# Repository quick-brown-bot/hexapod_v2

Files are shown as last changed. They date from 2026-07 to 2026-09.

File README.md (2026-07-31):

# Hexapod

An ESP32-powered hexapod robot built as a long-term robotics and embedded systems project.

The goal is not just to make a robot walk, but to learn and at the same time build a platform that is easy to experiment with, tune, and extend. Most robot behavior is configurable at runtime, control inputs are transport-independent, and the motion stack is organized into separated components.

The project combines firmware, hardware design, and system documentation in a single repository.

> 6 legs, 18 servos, ESP32 mainboard, distributed RP2040 leg controllers over
> an RS485 bus, per-servo current sensing.

This is a continuation of the original [Hexabot](https://github.com/quick-brown-bot/hexapod) project, developed here in
[`hexapod_v2`](https://github.com/quick-brown-bot/hexapod_v2). It differs from
the original mainly in electronics architecture — distributed RP2040 leg
controllers over RS485 instead of a single ESP32 driving all servos directly —
and adds new features such as per-servo current sensing.

---

## What Is In This Repository

The repository contains software and hardware assets used to develop and validate the robot.

```text
firmware/
├── mainboard/             ESP32 mainboard firmware (RS485 master)
├── leg/                   RP2040 leg controller firmware
└── mainboard_rs485_test/  Standalone RS485 bring-up/benchmark tool

hardware/
├── mainboard/             MainBoard schematic (ESP32 + IMU + RS485 master)
├── legboard/               LegBoard schematic (RP2040, servo PWM, current sensing)
└── powerboard/            MainPowerBoard schematic (battery, fusing, UBEC/SBEC)

docs/
├── architecture/          System architecture, hardware and mechanics
├── interfaces/            RS485, RPC, WiFi, Bluetooth, controller driver protocols
├── configuration/         Configuration platform design
├── development/           Build, flash, and dev workflow
└── plans/                 Project-wide backlog and research items
```

Mainboard firmware overview: [firmware/mainboard/README.md](firmware/mainboard/README.md)

The main firmware is built around a fixed 100 Hz control loop and a modular motion pipeline:

```text
Controller Input
        ↓
Gait Scheduler
        ↓
Foot Trajectory Generation
        ↓
Inverse Kinematics
        ↓
Motion Limiting
        ↓
Servo Outputs
```

---

## Current Technical Highlights

## Effort Summary

| Effort Area | Scope | Current Status | Notes |
| --- | --- | --- | --- |
| Locomotion Pipeline | Command mapping, gait scheduler, swing trajectory, whole-body IK | Implemented | Runs in a fixed 100 Hz control loop |
| KPP Motion Limits | Velocity, acceleration, jerk limiting and state estimation | Implemented | Runtime limits are configuration-backed |
| Controller Abstraction | Driver-agnostic core plus transport-specific drivers | Implemented | FlySky iBUS, Wi-Fi TCP, and Bluetooth Classic paths are present |
| RPC System | Queue-based command processing and config control | Implemented | Live inspection and runtime tuning are available |
| Configuration Platform | Namespace defaults, migration, discovery, persistence | Implemented | Core runtime namespaces are already consumed by modules |
| Configurator Tooling | External tuning and visualization UX | Planned | Firmware-side groundwork exists; UI work remains |

## Hardware Snapshot

- MCUs: ESP32 mainboard (FreeRTOS via ESP-IDF) + 6 × XIAO RP2040 (one per leg).
- Robot layout: 6 legs, 3 degrees of freedom per leg, 18 hobby servos total.
- Communication: RS485 multi-drop bus connecting the mainboard to all six leg controllers.
- Sensing: INA4181 4-channel current sensing per LegBoard for ground-contact detection.
- Power: dedicated MainPowerBoard with three UBECs (servo) and one SBEC (logic), fully isolated from logic power.
- Mechanical: custom 3D-printed chassis and leg parts.

## High-Level Architecture

```mermaid
flowchart LR
        Control[Controller stack]
        Config[RPC and config]
        App[Application loop]
        Loc[Locomotion]
        Limits[Motion limiting]
        Act[Actuation]
        Robot[Robot hardware]

        Control --> App
        Config --> App
        App --> Loc --> Limits --> Act --> Robot
        Config --> Control
```

- Controller stack: receives operator input from supported transports and normalizes it.
- RPC and config: handles runtime commands, parameter discovery, persistence, and save flows.
- Application loop: owns boot order and the 100 Hz control cycle.
- Locomotion: turns operator intent into gait phase, foot targets, and joint-space commands.
- Motion limiting: constrains commanded motion to configured dynamic envelopes.
- Actuation: maps joint commands to the PWM outputs that drive the robot.

### Runtime Configuration

Configuration is treated as a first-class subsystem rather than a collection of compile-time constants.

Parameters are organized into namespaces. Each namespace owns:

- parameter definitions,
- default values,
- validation rules,
- persistence behavior,
- migration logic,
- RPC discovery metadata.

The configuration manager provides:

- runtime parameter inspection,
- runtime modification,
- save/load operations,
- namespace registration,
- NVS persistence,
- version-aware migration support.

Robot geometry, calibration data, controller settings, motion limits, and other runtime behavior are loaded through this system rather than being hardcoded throughout the codebase.

### Motion Pipeline

The locomotion stack converts user commands into joint targets through a sequence of dedicated subsystems:

- gait scheduling,
- swing trajectory generation,
- inverse kinematics,
- velocity limiting,
- acceleration limiting,
- jerk limiting,
- servo actuation.

The motion loop runs at 100 Hz.

### Controller Abstraction

Controller transports are separated from locomotion.

Supported ingress paths currently include:

- FlySky iBUS,
- Wi-Fi TCP,
- Bluetooth Classic.

Each transport driver translates incoming data into a normalized controller state consumed by the motion system.

This allows locomotion, gait generation, and motion limiting to remain independent of transport-specific protocols.

### Hardware-Aware Design

The robot uses 18 servos arranged as three joints per leg:

- Coxa
- Femur
- Tibia

Servo signal generation is implemented on ESP32 using a combination of MCPWM and LEDC peripherals to fit within available hardware resources.

Power for logic and servos is separated to improve stability under heavy load.

---

## Engineering Problems Being Explored

This project is primarily a learning and engineering platform.

Current focus areas include:

- real-time control on resource-constrained hardware,
- gait generation and scheduling,
- inverse kinematics,
- motion smoothing and trajectory constraints,
- configuration architecture for embedded systems,
- transport-independent control interfaces,
- robotics software maintainability,
- practical servo-driven locomotion.

---

## Hardware Architecture

Distributed leg controllers with full separation of logic and servo power. The
architecture is defined and schematics are authored; firmware is in development.

- **Three boards**: MainBoard (ESP32 + IMU + RS485 master), LegBoard × 6 (XIAO
  RP2040, servo PWM, per-servo current sensing), MainPowerBoard (battery,
  fusing, UBEC/SBEC distribution).
- **The ESP32 does not generate servo PWM.** Joint commands are sent over RS485;
  each RP2040 generates PWM locally and interpolates between targets.
- **Per-servo current sensing** on every LegBoard enables ground-contact
  detection from current spikes without dedicated force sensors.
- **Servo current is fully isolated from the MainBoard** at the hardware level.

See [`docs/architecture/`](docs/architecture/) for the full architecture and interface documentation.

---

## Documentation

The repository contains detailed documentation covering implementation details and architecture decisions.

- [docs/architecture/SYSTEM_ARCHITECTURE.md](docs/architecture/SYSTEM_ARCHITECTURE.md)
- [docs/architecture/HARDWARE_AND_MECHANICS.md](docs/architecture/HARDWARE_AND_MECHANICS.md)
- [docs/interfaces/RS485_PROTOCOL.md](docs/interfaces/RS485_PROTOCOL.md)
- [docs/development/README.md](docs/development/README.md)
- [docs/interfaces/RPC_USER_GUIDE.md](docs/interfaces/RPC_USER_GUIDE.md)
- [docs/configuration/CONFIGURATION_PERSISTENCE_DESIGN.md](docs/configuration/CONFIGURATION_PERSISTENCE_DESIGN.md)
- [firmware/mainboard/README.md](firmware/mainboard/README.md)

Full documentation index: [docs/README.md](docs/README.md)

---

## Project Status

The project is under active development.

Current work focuses on improving locomotion quality, refining control architecture boundaries, and preparing the next generation of leg electronics while keeping the existing robot operational as a test platform.

---

## License

This repository uses Apache License 2.0 for the mainboard firmware.

License file location: [LICENSE](LICENSE)

Include the following notice in derivative works:

```text
Copyright 2025 Pawel Grudzien

Licensed under the Apache License, Version 2.0 (the "License");
you may not use this file except in compliance with the License.
You may obtain a copy of the License at

    http://www.apache.org/licenses/LICENSE-2.0

Unless required by applicable law or agreed to in writing, software
distributed under the License is distributed on an "AS IS" BASIS,
WITHOUT WARRANTIES OR CONDITIONS OF ANY KIND, either express or implied.
See the License for the specific language governing permissions and
limitations under the License.
```

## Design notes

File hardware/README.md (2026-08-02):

# Hexapod boards

Schematics for the [system architecture](../docs/architecture/SYSTEM_ARCHITECTURE.md):
distributed leg controllers with logic power separated from servo power.

Three boards:

| Board | Source | Role |
|---|---|---|
| [MainBoard](mainboard/) | [`mainboard_sch.py`](mainboard/mainboard_sch.py) | ESP32 + IMU + RS485 master + 6× RJ11. Logic & comms only. |
| [LegBoard](legboard/) | [`legboard_sch.py`](legboard/legboard_sch.py) | XIAO RP2040 + SP3485 + 3 servos + sensing. One per leg. |
| [MainPowerBoard](powerboard/) | [`powerboard_sch.py`](powerboard/powerboard_sch.py) | Battery → fuse/switch/protection → 3 UBECs + SBEC → legs. |

There's also one bench-only tool, not part of the robot itself:

| Board | Source | Role |
|---|---|---|
| [calboard](calboard/) | [`calboard_sch.py`](calboard/calboard_sch.py) | XIAO RP2040 + resistor ladder. Plugs into a LegBoard's servo connectors in place of real servos to calibrate its current sensing — see [`firmware/calboard/README.md`](../firmware/calboard/README.md) and [`tools/current_calibration/`](../tools/current_calibration/). |

These schematics are authored **as code** with the
[`hardware-schematics`](schematic/README.md) toolchain. The Python script is
the source of truth; `uuids.json` is the committed UUID registry that protects
the PCB layout across regenerations. Edit the `.py`, never the `.kicad_sch` by
hand.

## Regenerating

```bash
python hardware/mainboard/mainboard_sch.py
python hardware/legboard/legboard_sch.py
python hardware/powerboard/powerboard_sch.py
```

Each writes its `<board>.kicad_sch` and updates `<board>/uuids.json` (additions
only for unchanged parts). `hardware/_common.py` resolves symbol libraries:
stock KiCad libs from the install (override with `KICAD_SYMBOL_DIR`), plus the
in-repo libraries under [`symbols/`](symbols/) — the Seeed XIAO series
(`Seeed_Studio_XIAO_Series.kicad_sym`), the ESP32 module (`SymbolsLib.kicad_sym`),
and `Hexapod_V2.kicad_sym` (flattened standalone `RJ25` and `SP3485CN`, because
the stock library defines those as derived `(extends …)` symbols the code
importer cannot follow).

The boards are self-contained: symbol libraries, footprints, and the FreeCAD
model live here under [`symbols/`](symbols/), [`footprints/`](footprints/) and
[`models/`](models/); they do not depend on any shared top-level libraries.

## Inter-board connections

```text
MainPowerBoard.J_LOGIC (+5V) ──► MainBoard.J7 (SBEC_5V_IN)
MainBoard.J1..J6 (RJ11)      ──► LegBoard.J1 (UPLINK_RJ11)        ×6
MainPowerBoard.J1..J6 (+6V)  ──► LegBoard.J5 (SERVO_PWR_IN)       ×6
```

### RJ11 / RJ25 leg link (MainBoard ↔ LegBoard)

The physical cable is populated as a 4-wire link inside a 6P6C/RJ25 shell, so
pins 1 and 6 are intentionally left unconnected.

| Pin | Net | Function |
|-----|-----|---|
| 1 | — | unused |
| 2 | GND | Ground |
| 3 | RS485_A | RS485 A |
| 4 | RS485_B | RS485 B |
| 5 | +5V | Logic power |
| 6 | — | unused |

## MainBoard nets

| Net | Connects |
|-----|---|
| `+5V` | SBEC input (J7), ESP32 dev-board VIN, all six RJ11 pin 5 |
| `+3.3V` | ESP32 dev-board 3V3 output, SP3485 VCC, IMU, decoupling, EN pull-up |
| `GND` | global ground |
| `ESP_TXD` / `ESP_RXD` | ESP32 IO17/IO16 (UART2) ↔ SP3485 DI/RO |
| `RS485_DE` | ESP32 IO4 → SP3485 DE + ~RE (direction) |
| `RS485_A` / `RS485_B` | SP3485 A/B ↔ all six RJ11, 120 Ω term (R1) |
| `IMU_SDA` / `IMU_SCL` / `IMU_INT` | ESP32 IO21/IO22/IO34 ↔ IMU header (J9) |

MainBoard decoupling intent (implemented in schematic code): `C1` 10 uF on +5V at
power entry (close to J7/U1 VIN), `C2` 100 nF at ESP32 3V3 pins, `C3` 100 nF at
SP3485 VCC, `C4` 100 nF at IMU header power pins, and `C5` 10 uF bulk on +3.3V
near the ESP32 3V3-source/load hub.

IMU header J9 (`Conn_01x05`): 1 = +3.3V, 2 = GND, 3 = SDA, 4 = SCL, 5 = INT.

Footprints currently driven from the generator: `U1` uses
`Custom:ESP32_Dev_Board`, `J1..J6` use
`Connector_RJ:RJ25_Wayconn_MJEA-660X1_Horizontal`, `J9` uses
`Connector_PinHeader_2.54mm:PinHeader_1x05_P2.54mm_Vertical`, `U2` uses the
SOIC-8 SP3485 footprint, and the ordinary small R/C parts default to 0805.

## LegBoard nets

| Net | Connects |
|-----|---|
| `+5V` | RJ11 pin 5 logic power → XIAO VBUS (U1.14) |
| `+3.3V` | XIAO 3V3 out (U1.12) → SP3485 VCC, INA4181 VCC, decoupling |
| `+6V` | post-total-shunt servo bus; high-side **force** node feeding the three per-servo branch shunts and bulk cap C2 |
| `+6V_IN` | raw servo-power input (J5) ahead of the total shunt |
| `+6V_COXA` / `+6V_FEMUR` / `+6V_TIBIA` | post-branch-shunt servo supply rails (force) for J2 / J3 / J4 |
| `ITOT_SP` / `ITOT_SN` | Kelvin **sense** taps of total shunt R4 → INA IN+1 / IN-1 |
| `COXA_SP` / `COXA_SN` | Kelvin sense taps of coxa shunt R5 → INA IN+4 / IN-4 |
| `FEMUR_SP` / `FEMUR_SN` | Kelvin sense taps of femur shunt R3 → INA IN+2 / IN-2 |
| `TIBIA_SP` / `TIBIA_SN` | Kelvin sense taps of tibia shunt R2 → INA IN+3 / IN-3 |
| `GND` | global ground |
| `RP_TXD` / `RP_RXD` | XIAO P0/P1 (UART) ↔ SP3485 DI/RO |
| `RS485_DE` | XIAO P6/D4 → SP3485 DE + ~RE |
| `RS485_A` / `RS485_B` | SP3485 ↔ RJ11, 120 Ω term R1 (DNP except bus ends) |
| `COXA_PWM` / `FEMUR_PWM` / `TIBIA_PWM` | XIAO P3/P4/P2 → servo connectors J2/J3/J4 |
| `I_TOTAL_SENSE` | INA4181 channel 1 output → XIAO A0 |
| `I_FEMUR_SENSE` | INA4181 channel 2 output → XIAO A1 |
| `I_TIBIA_SENSE` | INA4181 channel 3 output → XIAO A2 |
| `I_COXA_SENSE` | INA4181 channel 4 output → XIAO A3 |

Servo connectors J2/J3/J4 (`Conn_01x03`): 1 = signal, 2 = branch +6V, 3 = GND.
J5 is a 2-pin screw terminal for servo power input. The four current shunts
`R2`/`R3`/`R4`/`R5` are **4-terminal (Kelvin) shunts** (`Device:R_Shunt`): pins
1/4 carry current, pins 2/3 are the sense taps. Each INA input reaches the shunt
over its own unique two-node `*_SP`/`*_SN` net, so the autorouter cannot merge
the three high-side taps (INA pins 6/15/17) through the shared `+6V` copper or
assign them current-rail trace widths. U3 (`INA4181A3IPWR`, gain 100) measures channel 1 across the total-leg shunt
`R4` (`+6V_IN`→`+6V`), channel 2 across femur `R3`, channel 3 across tibia
`R2`, channel 4 across coxa `R5`; IN+ is always on the higher-potential
(source) side. The generated sheet layout keeps the XIAO and INA
blocks as top-level anchors with the connector and power groups below for
readability.

> **Shunt placement must stay at rotation 0.** The schematic-as-code pin
> transform mismatches KiCad for off-axis pins at rotation 90/270 — the Kelvin
> sense pads land off the pin and the force pads swap. Verified via netlist
> export; keep the `Device:R_Shunt` placements un-rotated.

Footprints currently driven from the generator: `U1` uses
`Seeed_Studio_XIAO_Series:XIAO-RP2040-DIP`, `J1` uses
`Connector_RJ:RJ25_Wayconn_MJEA-660X1_Horizontal`, `U2` uses the SOIC-8
SP3485 footprint, `U3` uses `Custom:PW20_TEX`, `J2`/`J3`/`J4` use
`Connector_PinHeader_2.54mm:PinHeader_1x03_P2.54mm_Vertical`, `J5` uses
`TerminalBlock:TerminalBlock_MaiXu_MX126-5.0-02P_1x02_P5.00mm`, the four INA
shunts now use the 4-contact Kelvin footprint
`Resistor_SMD:R_Shunt_Ohmite_LVK12`, `C2` uses the through-hole radial candidate
`Capacitor_THT:CP_Radial_D8.0mm_P3.50mm` for an 8 mm diameter bulk capacitor, and
the ordinary small R/C parts default to 0805. Verify the LVK12 shunt power rating
and the capacitor lead pitch / body height against the exact parts before
freezing the PCB.

## MainPowerBoard nets

| Net | Connects |
|-----|---|
| `BATT_RAW`→`BATT_FUSED`→`+VMAIN` | battery → F1 fuse → Q1/Q2 parallel PMOS reverse-polarity stage → main rail |
| `+VMAIN` | feeds the three UBEC modules (J8/J9/J10), the SBEC (J11), monitor (J13), bulk C4 |
| `VSERVO1` | UBEC1 out → legs 1,2 (J1,J2), bulk C1, LED D2 |
| `VSERVO2` | UBEC2 out → legs 3,4 (J3,J4), bulk C2, LED D3 |
| `VSERVO3` | UBEC3 out → legs 5,6 (J5,J6), bulk C3, LED D4 |
| `+5V` | SBEC out (J11) → logic output (J12), LED D5 |
| `GND` | global ground |

UBEC/SBEC module headers (`Conn_01x04`): 1 = +VMAIN in, 2 = GND, 3 = regulated
out, 4 = GND. Monitor header J13 (`Conn_01x05`): +VMAIN, VSERVO1, VSERVO2,
VSERVO3, GND.

`F1` is a soldered-in (non-replaceable) SMD fuse, Schurter 3413.0331.22
(20A, time-lag, 1206/`Fuse:Fuse_1206_3216Metric`) — chosen over an automotive
mini-blade holder because TME stocks no SMD blade-fuse holder; the previous
`Custom:Fuse Holder Mini` THT holder footprint is unused now but left in the
library.

Footprints currently driven from the generator: `J7` (battery input) uses
`Connector_Wire:SolderWire-1.5sqmm_1x02_P7.8mm_D1.7mm_OD3.9mm` solder pads,
`J1..J6` use
`TerminalBlock:TerminalBlock_MaiXu_MX126-5.0-02P_1x02_P5.00mm`, and `J13` uses
`Connector_PinHeader_2.54mm:PinHeader_1x05_P2.54mm_Vertical`. Bulk caps use
`C1..C3`: `Capacitor_THT:CP_Radial_D13.0mm_P5.00mm` (2200 uF class) and `C4`:
`Capacitor_THT:CP_Radial_D8.0mm_P3.80mm` (1000 uF class). The status resistor /
LED parts default to 0805. Reverse-polarity protection uses two parallel
`FQP47P06` PMOS parts in `Package_TO_SOT_THT:TO-220-3_Vertical`.

Power-entry control is now low-current at SW1: the high-current path is
`BATT_FUSED -> Q1/Q2 -> +VMAIN`, while SW1 only drives the PMOS gates through
`R7=10k` + `Q3` (NPN pull-down), with `R6=100k` pull-up and `R5=100R` series
gate resistor for damping.

Pre-prototype hardening now added in-code:
- `R8=100k` from `NPN_BASE` to `GND` (base pull-down; avoids floating base when SW1 is open).
- `D6=15V` Zener between `PMOS_GATE` and `BATT_FUSED` (Vgs transient clamp).
- Optional `C5=100nF` from `PMOS_GATE_DRV` to `GND` (slows turn-on edge to soften inrush into ~7600 uF total bulk capacitance).

## PCB order tagging

Each board order placed with JLCPCB is tagged in git at the exact commit that
was sent to manufacture:

```
git tag pcb_order_<JLCPCB-order-ID> <commit>
```

Example: `pcb_order_W2026062121528170` points to the first legboard/mainboard
order. To inspect or check out any ordered revision:

```bash
git show pcb_order_W2026062121528170          # view commit
git checkout pcb_order_W2026062121528170      # restore that state
```

This makes it possible to diff the current schematic against what was actually
fabricated, or to flash firmware that matches the physical board on hand.

---

## Status / known limitations (first pass)

These are deliberate module-abstraction simplifications to refine in Eeschema
before fabrication:

* **Reverse-polarity protection** now uses two parallel PMOS parts (`Q1`/`Q2`,
  `FQP47P06`) to leave thermal headroom for high current, plus a low-current
  gate-driver stage (`Q3`, `R5`, `R6`, `R7`, `R8`) so SW1 does not switch inrush
  current directly.
* **UBEC / SBEC / IMU / current sensor** are represented as module headers, not
  discrete designs.
* **ERC** loads cleanly but reports expected violations: unused ESP32/XIAO GPIO
  and the ESP32 `VIN`/`SENSOR_*` pins are left open (add no-connect flags), and
  off-grid endpoints (the loose auto-layout is meant to be re-placed in
  Eeschema). Net-label connectivity is verified correct via exported netlist.
* **Remaining footprint work** is limited to the high-current / bulk power-path
  parts and the placeholder module headers; the ordinary V2 passives, ESP32,
  XIAO RP2040, RJ25 connectors, and the IMU header are now assigned in code.

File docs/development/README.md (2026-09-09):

# Development Setup

## Purpose

This document is the software-side starting point for development. The
project involves two separate firmware projects and two toolchains, and
hardware bring-up must follow a specific sequence because the mainboard and
six LegBoards depend on each other over RS485.

---

## Reading Before Starting

Read these first:

1. [../architecture/SYSTEM_ARCHITECTURE.md](../architecture/SYSTEM_ARCHITECTURE.md) — component split and RS485 communication architecture
2. [../architecture/HARDWARE_AND_MECHANICS.md](../architecture/HARDWARE_AND_MECHANICS.md) — board responsibilities, power topology, wiring
3. [../interfaces/RS485_PROTOCOL.md](../interfaces/RS485_PROTOCOL.md) — transaction model and frame format

---

## Repository Orientation

```
firmware/
  mainboard/       ESP32 firmware — motion control, RS485 master, RPC, config
  leg/             RP2040 firmware — servo PWM, interpolation, current sensing

docs/
  architecture/    SYSTEM_ARCHITECTURE.md, HARDWARE_AND_MECHANICS.md
  interfaces/      RS485_PROTOCOL.md
  development/     This file

hardware/
  mainboard/       ESP32 MainBoard schematic (Python source + KiCad output)
  legboard/        RP2040 LegBoard schematic
  powerboard/      MainPowerBoard schematic
```

---

## Development Environment

This project requires two toolchains side by side.

### Mainboard — ESP32 (ESP-IDF)

- ESP-IDF 5.x
- Visual Studio Code with the official ESP-IDF extension
- Target: ESP32

Setup:
1. Install ESP-IDF 5.x using the official Espressif tooling.
2. Install the ESP-IDF VS Code extension.
3. Configure the extension with the ESP-IDF tools path and Python environment.

`idf.py` is the canonical toolchain for this board and the one the bring-up
sequence and host tests assume. `firmware/mainboard/` also carries a
committed `platformio.ini` (`framework = espidf`, `src_dir = main`) that
builds the identical ESP-IDF project via `pio run` / `pio run --target
upload` — handy if you already have PlatformIO installed for the leg, but it
does not remove the ESP-IDF requirement (PlatformIO drives `idf.py`
underneath).

### Leg — RP2040 (PlatformIO + arduino-pico)

- PlatformIO with the VS Code PlatformIO extension
- Project root: `firmware/leg/`
- Framework: **arduino-pico** (Earle Philhower's Arduino core for RP2040)

arduino-pico sits directly on top of the Pico SDK — native `pico/stdlib.h`,
`hardware/uart.h`, `hardware/pwm.h`, and other SDK headers are fully accessible
alongside it. This gives Pico SDK-level control over UART timing, PWM, and DMA
while keeping the PlatformIO build system and upload tooling working.

Setup:
1. Install the PlatformIO VS Code extension.
2. Open `firmware/leg/` as a PlatformIO project.
3. PlatformIO installs the `raspberrypi` platform and arduino-pico core
   automatically on first build.

Both extensions can coexist in the same VS Code instance. Use the workspace
switcher or terminal context to target the correct project.

### Line Endings

This repo standardizes on **LF only**, enforced repo-wide by `.gitattributes`
(`* text=auto eol=lf`) — git normalizes any text file to LF on checkout and
commit regardless of the contributor's OS or editor, so a Windows checkout
(relevant here since the host-side RPC/config test suite targets Windows +
a live robot, see below) can't silently reintroduce CRLF. If an editor or
tool still writes CRLF into a tracked text file, `git status`/`git diff`
will show the whole file as changed even though nothing meaningful moved —
that's line-ending drift, not a real edit; re-run `git add --renormalize .`
(or configure the tool to write LF) rather than committing it.

---

## Mainboard Firmware

Firmware lives at `firmware/mainboard/`. The RS485 distributed-leg design adds
`hex_rs485_master` and a modified `hex_actuation` that writes to the command
buffer instead of PWM registers.

### Build, Flash, Monitor

From an ESP-IDF terminal in `firmware/mainboard/`:

```bash
idf.py build
idf.py flash
idf.py monitor
```

(Equivalently, `pio run` / `pio run --target upload` / `pio device monitor`
via the committed `platformio.ini` — same ESP-IDF build.)

The serial monitor shows boot logs, RS485 master task status, and any leg
communication events. Keep it open during RS485 bring-up.

### Host-Side Tests

The host-side pytest suite tests RPC and config flows over Wi-Fi.

```bash
pip install -r firmware/mainboard/test/requirements.txt
python -m pytest -q -p no:embedded firmware/mainboard/test/test_config_general_listing.py
```

Set the robot endpoint if not using defaults:

```bash
set HEXAPOD_IP=<robot_ip>
set HEXAPOD_PORT=<robot_port>
```

---

## Leg Firmware

Firmware lives at `firmware/leg/`. One binary is flashed to all six
LegBoards.

### Leg Addressing

Each RP2040 stores its leg address (1–6) in flash. The address is written
during the pre-mount calibration step, before the leg is physically attached
to the robot frame. All six LegBoards run identical firmware; the address
is the only per-board difference.

Calibration is performed over USB while the leg is on the bench. A
calibration tool (Python script over USB serial) connects to the RP2040,
writes the address and initial servo parameters to flash, and verifies the
stored values. Once calibrated and mounted, the leg uses RS485 exclusively
— USB is only needed for re-calibration or firmware updates.

See [Phase 3 in the bring-up sequence](#phase-3--first-leg-rj11-only-no-servo-power)
for how to verify the address is correctly set before mounting.

### Build

From a PlatformIO terminal in `firmware/leg/`:

```bash
pio run
```

### Flash

The XIAO RP2040 supports two flashing methods:

**UF2 drag-and-drop (recommended for bring-up):**
1. Hold the BOOTSEL button on the XIAO RP2040 while connecting USB.
2. A USB mass storage device (`RPI-RP2`) appears.
3. Copy the `.uf2` file from `.pio/build/<env>/` onto the drive.
4. The device reboots and runs the new firmware.

**PlatformIO upload (once the build environment is stable):**
```bash
pio run --target upload
```

### Monitor

```bash
pio device monitor --baud 115200
```

The leg firmware should log its address, parameter defaults, and RS485 receive
events on startup.

---

## Bring-Up Sequence

Bring up hardware in this order. Each phase must pass before the next begins.

### Phase 1 — MainPowerBoard (no MCUs connected)

1. Connect the battery through the master power switch.
2. Verify SBEC output: +5 V on the logic output header.
3. Verify UBEC outputs: +6 V on each leg servo power terminal.
4. Confirm all status LEDs (UBEC 1/2/3, SBEC) are lit.
5. Power off before connecting any MCU boards.

### Phase 2 — Mainboard Alone

1. Connect only the SBEC +5 V logic supply to the MainBoard.
2. Flash mainboard firmware over USB.
3. Open serial monitor. Confirm:
   - Config manager initializes.
   - RS485 master task starts.
   - Wi-Fi AP comes up (SSID visible on a nearby device).
4. Connect over Wi-Fi, run an RPC command to confirm the RPC layer is live.
5. At this point the mainboard will be logging RS485 timeouts for all six legs
   — this is expected. Confirm the timeout handling produces stale-entry markers
   rather than crashes.

### Phase 3 — First Leg (RJ11 only, no servo power)

1. Flash one RP2040 LegBoard with the correct address set (see Leg Addressing).
2. Connect the RJ11 cable between MainBoard port 1 and the LegBoard.
3. **Do not connect servo power yet.**
4. Open serial monitor on the RP2040 (USB). Confirm it is receiving RS485
   frames and responding.
5. On the mainboard monitor, confirm the telemetry buffer entry for leg 1 is
   updating (no longer stale).
6. Send a pull with `JOINT_POS` flag set and verify current joint positions
   appear in the telemetry response.

### Phase 4 — Servo Power for First Leg

1. Connect the MainPowerBoard servo output for legs 1/2 to the LegBoard.
2. Command a small angle change via RPC.
3. Verify the servo moves.
4. Verify coxa/femur/tibia current readings in telemetry change under load.

### Phase 5 — Remaining Legs

Repeat phases 3 and 4 for legs 2 through 6. Add one leg at a time. Verify
RS485 addressing is correct for each (the wrong address will produce no
response and a timeout on the master).

---

## RS485 Debugging

The RS485 bus carries text frames at 1 Mbps. It can be monitored directly
with a USB-to-RS485 adapter connected to the A/B lines and a terminal set to
1 000 000 baud.

Pull frames start with `>`, telemetry responses start with `<`. Frames end
with `\n` and carry a `*XX` CRC8 suffix. A serial monitor with hex display
helps verify CRC and frame boundaries.

Common failure modes:

| Symptom | Likely cause |
|---|---|
| All legs stale, no responses | Wiring (A/B swapped, no ground, missing power to LegBoard) |
| One leg stale, others OK | Wrong address on that LegBoard, or faulty RJ11 connection |
| Intermittent CRC failures | Bus termination missing or wrong, DE turnaround too short |
| Leg responds once then goes silent | RP2040 watchdog triggering, or DE pin misconfigured on LegBoard |

---

## Practical First Steps

For a new contributor:

1. Read the three architecture docs listed at the top of this file.
2. Set up both toolchains (ESP-IDF and PlatformIO) and verify each builds.
3. Flash the mainboard, confirm it boots to phase 2 state above.
4. Flash one leg, connect it, reach phase 3 state.
5. Only then start modifying firmware — you have a working reference baseline.

---

## Related Docs

- [../architecture/SYSTEM_ARCHITECTURE.md](../architecture/SYSTEM_ARCHITECTURE.md)
- [../architecture/HARDWARE_AND_MECHANICS.md](../architecture/HARDWARE_AND_MECHANICS.md)
- [../interfaces/RS485_PROTOCOL.md](../interfaces/RS485_PROTOCOL.md)
- [../interfaces/RPC_USER_GUIDE.md](../interfaces/RPC_USER_GUIDE.md)
- [../configuration/CONFIGURATION_PERSISTENCE_DESIGN.md](../configuration/CONFIGURATION_PERSISTENCE_DESIGN.md)
- [../../hardware/README.md](../../hardware/README.md)

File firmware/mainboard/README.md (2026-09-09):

<div align="center">

# Hexapod Mainboard Firmware (ESP32)

| Supported Targets | ESP32 |
| --- | ----- |

</div>

## Overview

This directory contains ESP-IDF firmware for the hexapod mainboard. It provides the core locomotion runtime, controller ingestion, transport-facing RPC path, and namespace-backed runtime configuration.

## Scope

- Fixed-step 100 Hz locomotion control loop.
- Motion limiting and servo actuation for the 18-DOF platform.
- Multi-transport controller ingress (FlySky iBUS, Wi-Fi TCP, Bluetooth Classic).
- Runtime configuration through hex_config_manager namespaces.

## Directory Map

- main/: top-level bootstrapping and loop orchestration.
- components/: runtime modules split by subsystem.
- test/: host-side integration tests for RPC/config behavior.
- ../../docs/: architecture and protocol documentation shared across the monorepo.

## Mainboard Docs

- Documentation hub: [../../docs/README.md](../../docs/README.md)
- Architecture: [../../docs/architecture/SYSTEM_ARCHITECTURE.md](../../docs/architecture/SYSTEM_ARCHITECTURE.md)
- Configuration persistence: [../../docs/configuration/CONFIGURATION_PERSISTENCE_DESIGN.md](../../docs/configuration/CONFIGURATION_PERSISTENCE_DESIGN.md)
- RPC user guide: [../../docs/interfaces/RPC_USER_GUIDE.md](../../docs/interfaces/RPC_USER_GUIDE.md)

## Build And Flash

Run from this directory in an ESP-IDF-enabled terminal:

```bash
idf.py build
idf.py flash
idf.py monitor
```

`idf.py` is the canonical path. The committed `platformio.ini` here also
wraps this ESP-IDF project (`framework = espidf`), so `pio run` /
`pio run -t upload` build the same firmware via ESP-IDF if you already have
PlatformIO set up for the leg toolchain.

## Host-Side Tests

Install requirements:

```bash
pip install -r test/requirements.txt
```

Run one focused test module:

```bash
python -m pytest -q -p no:embedded test/test_config_general_listing.py
```

## License

Apache License 2.0. See [LICENSE](../../LICENSE).

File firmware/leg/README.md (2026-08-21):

# LegBoard Firmware (RP2040)

RP2040 firmware for a single hexapod leg. One binary runs on all six
LegBoards; each board differs only by its stored RS485 address.

The LegBoard is an RS485 slave: it receives joint-angle targets from the ESP32
MainBoard, interpolates between them locally for smooth motion, drives three
servos, samples per-servo current, and answers every pull with a telemetry
response. If the bus goes silent it holds position (watchdog).

See:
- [`docs/architecture/HARDWARE_AND_MECHANICS.md`](../../docs/architecture/HARDWARE_AND_MECHANICS.md) — pins, power, mechanics
- [`docs/interfaces/RS485_PROTOCOL.md`](../../docs/interfaces/RS485_PROTOCOL.md) — wire protocol
- [`docs/architecture/SYSTEM_ARCHITECTURE.md`](../../docs/architecture/SYSTEM_ARCHITECTURE.md) — system context
- [`docs/development/README.md`](../../docs/development/README.md) — toolchain & bring-up

## Toolchain

PlatformIO with the **arduino-pico** core (Earle Philhower). The official
PlatformIO `raspberrypi` platform ships only the mbed core and a couple of
boards, so `platformio.ini` uses the maxgerhardt platform fork plus
`board_build.core = earlephilhower`. This core sits directly on the Pico SDK,
so the firmware uses native `hardware/uart.h`, `hardware/pwm.h`, and
`hardware/adc.h` alongside Arduino APIs.

```bash
pio run                       # build
pio run --target upload       # flash (or drag the .uf2 via BOOTSEL)
pio device monitor            # USB serial (calibration interface)
```

## Module Layout

```
src/
  config.h       Pin map, loop rate, parameter and calibration defaults
  protocol.h/.c  RS485 frame parse/build + CRC-8/SMBus (host-testable, no HW deps)
  rs485.h/.cpp   UART0 half-duplex transport with manual DE turnaround
  interp.h/.c    Local LINEAR / cubic-Hermite interpolation between targets
  servo.h/.cpp   Hardware PWM at 50 Hz, angle->pulse via per-servo calibration
                 (PWM neutral/center is flash-persisted per joint, USB PWMNEUTRAL)
  current.h/.cpp INA4181 current sensing via the RP2040 ADC
  persist.h/.cpp Flash-backed leg address + current calibration (arduino-pico EEPROM,
                 two independent partitions)
  status_led.h/.cpp  Onboard LED: blinks red 2 Hz while uncalibrated, off once calibrated
  loopstat.h/.cpp    Measures the actual achieved loop()/control-step Hz (LOOPSTAT?)
  calib.h/.cpp   Minimal USB-serial bring-up interface (set leg address)
  main.cpp       Wiring: RS485 request/response + fixed-rate control loop
test/
  host/          Host unit test for the protocol module (run where gcc exists)
```

## Design Notes

- **Protocol parity.** `proto_crc8()` and the frame formats must stay
  byte-for-byte identical to the ESP32 master
  (`firmware/mainboard/components/hex_rs485_master`). The CRC examples in
  `RS485_PROTOCOL.md` are real CRC-8/SMBus values and double as test vectors.
- **DE turnaround.** arduino-pico has no hardware auto-DE. `rs485_send()` drives
  the DE pin manually and polls the UART BUSY flag before releasing it, so the
  final CRC byte is not truncated at 1 Mbps.
- **Silence is the protocol.** On CRC failure or an address mismatch the leg
  sends nothing; the master treats silence as a timeout. The leg never NAKs.
- **Persistence split.** Only the leg address, current-sense calibration, and
  per-joint PWM neutral (center) are stored in flash, in two independent
  EEPROM.h partitions (`persist.cpp`) so resetting one doesn't touch the
  other. Runtime parameters (move duration, watchdog timeout, interpolation
  mode, joint limits) default in firmware and are re-applied by the ESP32 on
  recovery — matching the protocol doc's "simplest first" approach.
  Current-sense calibration and PWM neutral are both set locally over USB
  (`CURCAL`, `PWMNEUTRAL`) only — they're board/leg-specific constants the leg
  owns, not something the ESP32 needs to know or re-apply (the RS485 protocol
  only ever carries joint angles in degrees, never raw pulse widths), so they
  deliberately have no RS485 counterpart. See
  `docs/development/LEG_CALIBRATION.md`.
- **Uncalibrated-board marker.** The leg address defaults to `0`, which is
  not a valid RS485 address (the protocol uses 1-6) — it means "never
  assigned an address." A board at address 0 blinks its onboard LED red at
  2 Hz (`status_led.cpp`) and never responds to any RS485 pull (no master
  ever addresses leg 0); the LED goes off immediately once `ADDR <1-6>` is
  run over USB, no reboot required.
- **Interpolation.** LINEAR is the default (easy to verify during bring-up);
  cubic Hermite is enabled via the `INTERP_MODE` parameter.
- **PWM neutral (center) calibration.** A leg's true physical zero-degree
  pose isn't always reachable at exactly the default 1500us, since a servo
  horn can't always be mounted perfectly centered on a given leg's build.
  `servo_write_angle()`'s angle->pulse mapping is anchored at
  `pwm_neutral_us` (angle 0 -> that pulse), with independent linear spans out
  to `pwm_min_us`/`pwm_max_us` on either side, so recalibrating the center
  doesn't distort the endpoints. Persisted per joint (`PWMNEUTRAL?` /
  `PWMNEUTRAL <joint 0-2> <us>`, `calib.cpp`), applied live with no reboot;
  see `tools/leg_configurator.py --mode servo` for the interactive jog +
  persist + direction-check flow, and `docs/development/LEG_CALIBRATION.md`.
  Per-joint sign (`invert`, +1/-1) is persisted the same way (`INVERT?` /
  `INVERT <joint 0-2> <1|-1>`) — the direction-check step now asks what
  direction each nudge produced and offers to flip and persist it on the
  spot. Angle range (`angle_min_deg`/`angle_max_deg`) is still compile-time
  only — see Bring-Up TODO below.
- **Current smoothing.** `current_sample()` runs at 1 kHz but the ESP32 only
  pulls each leg ~every 10 ms (100 Hz); without smoothing, RS485 telemetry
  would report whichever single 1 kHz sample happened to land at poll time.
  `current.cpp` smooths the *calibrated* current only (`CURRAW?`'s raw
  mV/counts always stay unfiltered, for calibration) with a runtime-selectable
  strategy, since per-servo current spikes are also the intended
  touchdown-detection signal (`docs/architecture/HARDWARE_AND_MECHANICS.md`)
  and heavier averaging blunts/delays them:
  - `CURFILT EMA [alpha 0-1]` (default) — exponential moving average,
    `DEFAULT_CURRENT_EMA_ALPHA` in config.h (0.4, ~2 ms time constant).
    Tunable at runtime; lower alpha = more smoothing/latency, 1.0 =
    unfiltered.
  - `CURFILT BOXCAR <n 1-32>` — flat N-sample moving average
    (`CURRENT_BOXCAR_MAX_N`/`DEFAULT_CURRENT_BOXCAR_N`, default N=10). Much
    stronger, uniform noise reduction, at the cost of a touchdown spike
    potentially only becoming clearly visible about one window late (e.g.
    ~20 ms at N=10 instead of ~10 ms).

  Persisted in the `calib` EEPROM partition (unlike MOVE_DURATION/
  WATCHDOG_TIMEOUT/INTERP_MODE — this is a board-level current-sensing
  setting, not something the ESP32 re-applies) — survives reboot, set over
  USB (`CURFILT?`/`CURFILT`). Switching mode or N persists the change and
  resets the filter state.

## Bring-Up Status / TODO

Builds clean; not yet validated on hardware. Known follow-ups:

- ADC current-sense channel mapping was verified against real hardware and
  the schematic 2026-08-02: the coxa/femur/tibia current-sense pins are
  **not** wired in alphabetical order (`I_FEMUR_SENSE`→A1, `I_TIBIA_SENSE`→A2,
  `I_COXA_SENSE`→A3) — `current.cpp`'s `kAdcPhysicalInput[]` now compensates.
  See `config.h`'s current-sense comment and
  `docs/architecture/HARDWARE_AND_MECHANICS.md`.
- Status LED polarity (`STATUS_LED_ACTIVE_LOW` in `config.h`) is assumed
  common-anode (LOW = on) per the XIAO RP2040's published pinout; **verify on
  real hardware** — invert if the LED behaves backwards (on when calibrated).
- Per-channel current calibration (scale + offset) is persisted in flash and
  defaults to the previous placeholder (`DEFAULT_ISENSE_MA_PER_MV = 1.0`,
  `DEFAULT_ISENSE_OFFSET_MA = 0.0`) until set. The USB calibration command
  set now covers leg address (`ADDR`, `STATUS?`, `PING`), raw pulse-width
  override for bring-up (`PWM`), and current calibration (`CURRAW?`,
  `CURCAL?`, `CURCAL`) — see `tools/leg_configurator.py` /
  `docs/development/LEG_CALIBRATION.md` for the guided address + resistor-based
  calibration wizard that drives these commands directly over the leg's own
  USB serial, `tools/legboard_current_monitor.py` for a live in-place
  readout of all 4 channels (handy for manual wiring/behavior checks), or
  `tools/current_calibration/` for the automated bench workflow using the
  calibration adapter board (`hardware/calboard/`).
- Servo PWM neutral (center) and per-joint sign (`invert`) are now persisted
  and settable over USB (`PWMNEUTRAL`, `INVERT`, `tools/leg_configurator.py
  --mode servo` -- also runs a gentle per-joint direction check, offering to
  flip+persist `invert` right there if the observed direction doesn't match
  the mainboard IK's convention, and an optional extended range walk).
  `DEFAULT_PWM_MIN_US`/`MAX_US` were corrected from the generic SG90-style
  1000/2000us assumption to 500/2500us, this servo's actual rated pulse
  width (measured on hardware: the old range only reached ~19-51 deg actual
  for a commanded 60/-90 deg). Angle range (`angle_min_deg`/`angle_max_deg`,
  still ±90°) remains compile-time only; a full USB calibration tool for that
  is still planned.
- Cubic interpolation's velocity estimation has untested edge cases (first
  command, post-watchdog restart); prove LINEAR on hardware first.

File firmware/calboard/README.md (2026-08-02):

# Calibration Adapter Board Firmware (RP2040)

Bench-only firmware for the current-sensor calibration adapter board
(`hardware/calboard/`). This board is **not part of the robot** — it plugs
into a single LegBoard's servo connectors (J2/J3/J4) in place of real
servos, so the LegBoard's INA4181 current sensing can be calibrated against
a known load instead of a multimeter and manual math each time.

See:
- [`hardware/calboard/calboard_sch.py`](../../hardware/calboard/calboard_sch.py) — schematic (pin map source of truth)
- [`tools/current_calibration/`](../../tools/current_calibration/) — host script that drives this board + a LegBoard together
- [`firmware/leg/src/calib.cpp`](../leg/src/calib.cpp) — LegBoard-side `PWM`/`CURRAW?`/`CURCAL` commands this board's PWM decode pairs with

## How it works

Each of the 3 channels (coxa/femur/tibia) has its own 3-pin header matching
a LegBoard servo connector's pinout (signal / +6V branch / GND). The signal
pin feeds a GPIO edge-interrupt PWM decoder (`pwm_capture.*`); the decoded
pulse width (1000-2000us) maps to a 0-15 step, which selects a combination
of 4 binary-weighted resistor legs via two daisy-chained 74HC595 shift
registers (`ladder.*`). A resistor divider on the branch rail feeds back into
the RP2040 ADC (`adc_readback.*`) so the true load current is computed as
`I = V_measured / R_effective(step)` — accounting for rail sag under load —
rather than assumed from a fixed 6V.

## Toolchain

Same as `firmware/leg/` — PlatformIO with the arduino-pico core:

```bash
pio run                       # build
pio run --target upload       # flash
pio device monitor            # USB serial command interface
```

## Module Layout

```
src/
  config.h          Pin map, PWM decode range, ladder resistor values (placeholder — see below)
  pwm_capture.h/.cpp GPIO-interrupt PWM pulse-width capture, one channel per servo connector
  ladder.h/.cpp     Shift-register bit-banging + effective-resistance lookup table
  adc_readback.h/.cpp Branch rail voltage readback
  usbserial.h/.cpp  Minimal ASCII command interface (mirrors firmware/leg/src/calib.cpp's style)
  main.cpp          Wiring
```

## USB Commands

```
PING                     -> PONG <fw>
STATUS?                  -> identity
READ?                    -> per-channel: step, R_ohm, V, I_mA, mode (auto/manual)
STEP <ch 0-2> <n 0-15>   -> manual load override (bring-up/standalone testing)
AUTO <ch 0-2>            -> resume PWM-decode-driven control
HELP
```

Each channel defaults to `auto` mode (load selected by the incoming PWM
signal). `STEP` is for bringing up/testing this board on its own before
wiring it to a LegBoard.

## Bring-Up Status / TODO

Builds clean; not yet validated on hardware — no physical board has been
fabricated yet.

- **Resistor ladder values in `config.h` are placeholders** (`LADDER_R1..R4_OHM`),
  sized for a modest ~27-490 mA bench-test current range at 6V. Review
  against the actual servos' expected current draw, and check resistor
  power ratings before fab — `LADDER_R4_OHM` alone can dissipate ~1.6W at
  6V and needs a real power resistor (TO-220 / 2512 chip), not a small
  0805/1206 part.
- `VSENSE_DIVIDER_RATIO` in `config.h` is a placeholder; set it from the
  schematic's actual divider resistor values once chosen.
- Pin map must be verified against `hardware/calboard/calboard_sch.py`
  before wiring.

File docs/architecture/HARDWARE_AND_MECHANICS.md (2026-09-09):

# Hardware And Mechanics — V2

## Purpose

This document collects the physical robot context that supports the V2 firmware
architecture: board responsibilities, power topology, communication wiring,
actuator layout, and the mechanical model assumed by the motion stack.

For schematic-level detail — net tables, footprints, known ERC issues — see
[`hardware/README.md`](../../hardware/README.md).

---

## Hardware Summary

V2 introduces three dedicated PCBs replacing the single board of V1.

| Board | MCU | Role |
|---|-----|---|
| MainBoard | ESP32 | Motion control, IMU, RS485 master, logic power distribution |
| LegBoard (×6) | XIAO RP2040 | Local servo PWM, current sensing, RS485 slave |
| MainPowerBoard | — | Battery input, fusing, UBEC/SBEC modules, servo power distribution |

Key differences from V1:
- Servo PWM is no longer generated by the ESP32. Each LegBoard generates PWM
  locally for its three servos.
- Communication between MainBoard and LegBoards is over a shared RS485 bus
  carried by RJ11 cables.
- Per-servo current is measured on each LegBoard via dedicated sense amplifiers
  and reported back to the ESP32.
- High-current servo loads are isolated from the MainBoard at the hardware
  level.

---

## Board Responsibilities

### MainBoard

Central logic and communication controller.

- Hosts the ESP32: gait generation, inverse kinematics, body stabilisation, IMU
  processing, controller input, RS485 master.
- Hosts the IMU. All orientation processing is centralised here; LegBoards have
  no orientation awareness.
- SP3485 RS485 transceiver with direction control on ESP32 IO4 (`RS485_DE`).
- Six RJ11 leg interfaces (one per leg), carrying logic power and RS485.
- Receives SBEC 5 V logic supply and distributes it to all LegBoards via RJ11.
- Does not carry servo current.

Firmware-relevant pin assignments:

| Signal | ESP32 pin |
|---|---|
| RS485 TX (UART2) | IO17 |
| RS485 RX (UART2) | IO16 |
| RS485 DE | IO4 |
| IMU SDA | IO21 |
| IMU SCL | IO22 |
| FlySky iBUS RX (UART1) | GPIO5 |

There is no dedicated RC-receiver connector on the MainBoard yet. The FlySky
iBUS signal is currently a flying-wire tap on the ESP32 module's **GPIO5**
pad (board silk "D5"); the receiver is powered from a UBEC with its ground
bonded to logic ground. Confirmed receiving valid iBUS frames with
`firmware/mainboard_ibus_test`, and it is the `controller` namespace default
`flysky_rx_gpio = 5`.

GPIO5 is a boot-strapping pin, but iBUS idles high so a powered receiver
does not disturb boot. Note "GPIO5" vs "GPIO34": ESP32 *package pin* 34 is
GPIO5 -- chip-level pinout diagrams that box the package-pin number next to
"GPIO5" are the source of a common mix-up. GPIO34 is a different, unused
input-only pad. A proper 3-pin receiver header (5V / GND / signal) is a
pending schematic change; if it lands on GPIO34 instead, update the default.

### LegBoard

One per leg. Intelligent local actuator controller.

- Hosts a Seeed XIAO RP2040.
- SP3485 RS485 transceiver; direction control on XIAO P6/D4 (`RS485_DE`).
- Receives commands over RS485, generates servo PWM locally for coxa, femur,
  and tibia joints.
- INA4181 4-channel current sense amplifier: one channel per servo plus a
  total-leg channel. Current readings are reported back to the ESP32 with each
  telemetry response.
- Watchdog on RS485 communication timeout: holds last commanded position or
  moves to a safe posture if the bus is silent for longer than the configured
  timeout.
- Performs local trajectory interpolation between received motion targets,
  producing smooth servo motion at a higher rate than the RS485 command rate.

Firmware-relevant pin assignments (XIAO RP2040):

| Signal | XIAO pin |
|---|---|
| RS485 TX (UART) | P0 |
| RS485 RX (UART) | P1 |
| RS485 DE | P6 / D4 |
| Coxa PWM | P3 |
| Femur PWM | P4 |
| Tibia PWM | P2 |
| Total current sense | A0 |
| Femur current sense | A1 |
| Tibia current sense | A2 |
| Coxa current sense | A3 |

**Verified against real hardware and corrected 2026-08-02** — this table
previously listed the coxa/femur/tibia current-sense pins in alphabetical
order (A1/A2/A3), which does not match `hardware/legboard/legboard_sch.py`'s
actual net wiring (`I_FEMUR_SENSE`→A1, `I_TIBIA_SENSE`→A2, `I_COXA_SENSE`→A3).
Firmware compensates for this in `firmware/leg/src/current.cpp`
(`kAdcPhysicalInput[]`) rather than relying on ADC channel number matching
joint identity — see that file's comment for the full mapping.

### MainPowerBoard

Responsible for all high-current power distribution. No MCU.

- Battery input with main fuse, reverse-polarity protection (PMOS), and master
  power switch.
- Three UBEC modules: servo power distributed in pairs to the six LegBoards.
- One SBEC module: 5 V logic supply to MainBoard.
- Bulk capacitance per UBEC output to absorb transient servo loads.
- Monitor header exposing battery voltage and all UBEC output voltages.
- Status LEDs: UBEC 1/2/3 present, SBEC present.

---

## Power Architecture

Logic and servo power are completely separated.

### Logic Power Path

```
LiPo → MainPowerBoard SBEC → MainBoard +5V rail → RJ11 pin 5 → LegBoard XIAO VBUS
```

Powers: ESP32, IMU, SP3485 transceivers on all boards, XIAO RP2040s, INA4181
sense amplifiers.

### Servo Power Path

```
LiPo → MainPowerBoard → UBEC 1 → LegBoards 1 and 2
                      → UBEC 2 → LegBoards 3 and 4
                      → UBEC 3 → LegBoards 5 and 6
```

Servo power enters each LegBoard on a dedicated 2-pin screw terminal and is
distributed through the on-board current shunts to the three servo connectors.
Servo current never passes through the MainBoard.

**Architectural rule: servo current must never flow through the MainBoard.**
MainBoard carries logic power, RS485 signals, and IMU signals only.

---

## Inter-Board Connections

### RJ11 Leg Link (MainBoard ↔ LegBoard)

Physical cable: 4-wire link inside a 6P6C / RJ25 shell. Pins 1 and 6 are
unpopulated.

| Pin | Net | Function |
|-----|-----|---|
| 1 | — | unused |
| 2 | GND | Ground |
| 3 | RS485\_A | RS485 differential A |
| 4 | RS485\_B | RS485 differential B |
| 5 | +5V | Logic power to LegBoard |
| 6 | — | unused |

One RJ11 cable per leg. The RS485 bus is a multi-drop line shared across all
six legs; all six LegBoards are addressable from the single SP3485 transceiver
on the MainBoard.

### Servo Power (MainPowerBoard ↔ LegBoard)

2-pin screw terminal on each LegBoard. Carries the regulated UBEC output
voltage (nominally 6 V) to that leg's servo bus.

### Logic Output (MainPowerBoard ↔ MainBoard)

4-pin header on the MainPowerBoard (`J_LOGIC`) to the MainBoard SBEC input
(`J7`). Carries the 5 V SBEC output.

---

## Control Frequencies

| Subsystem | Rate | Responsibilities |
|---|---|---|
| MainBoard (ESP32) | ~100 Hz | IMU update, gait generation, IK, trajectory generation, RS485 command dispatch |
| LegBoard (RP2040) | ~500–1000 Hz | Local interpolation, servo PWM update, current sampling, watchdog |

The RP2040 internal loop rate is independent of the RS485 command rate. It
interpolates between received motion targets at its own rate to produce smooth
servo motion, tolerating short gaps in RS485 communication without visible
stepping.

---

## Mechanical Layout

Unchanged from V1. Each leg has three joints:

1. **Coxa** — yaw and horizontal reach.
2. **Femur** — main pitch lift motion.
3. **Tibia** — distal extension and stance height control.

The robot uses a custom 3D-printed frame and leg structure sized around
standardised servo dimensions and the target stance geometry.

---

## Nominal Link Geometry

Coxa and tibia unchanged from V1. Femur corrected to this hexapod version's
actual length (was 0.088 m).

| Link | Length |
|---|---|
| Coxa | 0.068 m |
| Femur | 0.080 m |
| Tibia | 0.127 m |

These dimensions define the nominal leg model used by inverse kinematics and
related runtime configuration.

---

## Coordinate Conventions

Unchanged from V1.

- Body frame: `+X` forward, `+Y` left, `+Z` up.
- Leg-local planning frame: leg mount transforms rotate body-frame targets into
  each leg's local coordinate system before IK is solved.

The exact per-leg mount poses are part of the robot configuration domain and
are consumed by the motion stack at runtime.

## Joint Angle Sign Convention

The conventions above describe the *input* to `leg_ik_solve()`
(`hex_kinematics/leg.c`) — the Cartesian foot target. The *output* joint
angles (coxa/femur/tibia, `leg_angles_t`) have their own sign convention,
which isn't stated anywhere as prose — it falls out of the IK formula itself,
and only tibia has an inline code comment. Derived and confirmed on real
hardware during leg 1 bring-up (2026-08-21):

- **Coxa** (hip yaw): positive angle is a counter-clockwise rotation about
  `+Z`, viewed from above — i.e. from "straight out" (`+X`) toward "forward"
  (`+Y`), per the right-hand rule on the right-handed leg-local frame above.
  This is a geometric property of the frame itself, universal across all six
  legs; what it means in body-frame terms ("right" vs "left") depends on each
  leg's mount rotation, so there's no single answer like "positive = right"
  that holds for every leg (it happened to hold for leg 1's particular mount
  orientation).
- **Femur** (hip pitch): positive angle raises the foot (`+Z`, up). Not
  stated in a code comment — derived numerically from `leg_ik_solve()`'s
  formula: at the nominal link lengths above, a foot target 2 cm higher (same
  horizontal reach) computes roughly a **+10°** femur delta.
- **Tibia** (knee): positive angle lowers the foot (`-Z`, down) — explicit in
  `leg_ik_solve()`'s comment ("increasing angle corresponds to bending the
  leg downward... foot lowers"), and confirmed by the same numeric check: a
  foot target 2 cm lower computes roughly a **+6°** tibia delta.

**This is the IK model's convention — it is not automatically what a given
servo does when commanded that same signed angle.** Nothing about a leg's
physical assembly (which way a horn is splined on, which way a servo is
mounted) guarantees its raw wire-level positive direction already matches
this model. Each LegBoard applies its own per-joint `invert` (`+1`/`-1`,
`firmware/leg/src/servo.cpp`, persisted per joint — see
[`LEG_CALIBRATION.md`](../development/LEG_CALIBRATION.md) "Gentle direction
check") specifically to reconcile the two. On leg 1, coxa's raw sign already
matched this convention (positive = right, for that leg's mount
orientation), but femur and tibia were both found inverted relative to it
and corrected via `INVERT`.

Since `hex_actuation`'s `robot_execute()` sends whichever angles
`whole_body_control_compute()` (IK) or an RPC `joint` override produces
straight to `rs485_master_set_leg_angles()` with no sign massaging in
between, a leg's `invert` calibration is what makes a raw wire-level test
(e.g. the mainboard RPC `joint <leg> <coxa> <femur> <tibia>` command,
`tools/joint_direction_test.py`) agree with what the gait/IK stack expects —
run that test *after* `invert` is calibrated, not before, or the directions
you observe will describe the servo wiring, not the IK model.

---

## Why This Matters For Firmware

**No PWM peripheral budget constraint on the ESP32.** V1 required mixing MCPWM
and LEDC to produce 18 servo signals. In V2 the ESP32 produces no servo PWM;
all 18 signals are generated locally on the six LegBoards.

**RS485 bus latency budget shapes the comm task design.** The `hex_rs485_master`
task sends and polls each leg sequentially. Per-leg transaction time (baud rate,
frame sizes, DE turnaround, RP2040 response latency) determines the telemetry
refresh rate and must be sized so that current data is fresh enough for
touchdown detection. See [`../interfaces/RS485_PROTOCOL.md`](../interfaces/RS485_PROTOCOL.md) for the protocol
design.

**Per-servo current is the primary ground-contact signal.** The INA4181 on each
LegBoard measures current through each servo independently. A current spike on
the tibia (or femur) servo is the intended proxy for leg touchdown. This data
is returned in the telemetry response of every RS485 transaction and stored in
the `hex_rs485_master` telemetry buffer for use by the locomotion stack.

**RP2040 interpolation decouples servo smoothness from RS485 rate.** The
LegBoard does not require a new command every servo PWM cycle. It interpolates
locally between received targets, so RS485 bandwidth can be traded against
servo command granularity without visible motion degradation.

**Watchdog behavior is a safety boundary.** If the RS485 bus goes silent, each
LegBoard independently holds its last commanded position or transitions to a
safe posture after a configured timeout. This means a firmware crash or bus
fault on the ESP32 does not leave servos uncontrolled.

---

## Related Docs

- [SYSTEM_ARCHITECTURE.md](SYSTEM_ARCHITECTURE.md)
- [../interfaces/RS485_PROTOCOL.md](../interfaces/RS485_PROTOCOL.md) *(to be written)*
- [../../hardware/README.md](../../hardware/README.md) — schematic detail, net tables, footprints
- [../configuration/CONFIGURATION_PERSISTENCE_DESIGN.md](../configuration/CONFIGURATION_PERSISTENCE_DESIGN.md)

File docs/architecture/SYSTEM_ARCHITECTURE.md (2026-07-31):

# Hexapod V2 System Architecture

## Purpose

This document is the firmware architecture reference for Version 2.

It describes:
- which firmware components make up the V2 system,
- what changed from V1 and why,
- how data moves through the runtime,
- how the RS485 communication task decouples leg communication from the motion loop.

For hardware topology, power distribution, and board responsibilities see
[HARDWARE_AND_MECHANICS.md](HARDWARE_AND_MECHANICS.md).

---

## What Differs From V1

V2 firmware is structurally identical to V1 with one significant addition: the
motion stack no longer drives servo hardware directly. Instead `hex_actuation`
writes desired joint angles to a shared command buffer, and a new
`hex_rs485_master` component owns a dedicated FreeRTOS task that sends those
angles to the six RP2040 leg controllers and immediately polls telemetry back
from each leg — all without blocking the 100 Hz locomotion loop.

Everything else — controller and transport stack, RPC and configuration stack,
gait scheduling, kinematics, motion limiting — is unchanged from V1.

---

## 1. System At A Glance

```mermaid
flowchart LR
    App[main app bootstrap and loop]

    subgraph Motion[Motion Stack]
        Loc[hex_locomotion]
        Lim[hex_motion_limits]
        Act[hex_actuation]
        Kin[hex_kinematics]
        RobotCfg[hex_robot_config]
    end

    subgraph RS485[RS485 Communication]
        RS485M[hex_rs485_master]
        CmdBuf[[Command buffer\n6x joint angles]]
        TelBuf[[Telemetry buffer\n6x current + status]]
    end

    subgraph Control[Controller and Transport]
        Core[hex_controller_core]
        Fly[hex_controller_driver_flysky_ibus]
        WifiDrv[hex_controller_driver_wifi_tcp]
        BtDrv[hex_controller_driver_bt_classic]
        WifiAp[hex_wifi_ap]
    end

    subgraph RPC[RPC and Config]
        RpcCore[hex_rpc_core]
        RpcTx[hex_rpc_transport]
        CfgMgr[hex_config_manager]
        Shared[hex_shared_types]
    end

    App --> Loc --> Lim --> Act
    Loc --> Kin
    Loc --> RobotCfg
    Lim --> Kin
    Lim --> RobotCfg
    Act --> RobotCfg
    Act --> CmdBuf
    CmdBuf --> RS485M
    RS485M --> TelBuf
    TelBuf --> Loc

    Fly --> Core
    WifiDrv --> Core
    BtDrv --> Core
    WifiDrv --> RpcTx
    BtDrv --> RpcTx
    WifiAp --> WifiDrv

    RpcCore --> RpcTx
    RpcCore --> CfgMgr
    RpcCore --> Core

    Shared --> Core
    Shared --> RpcCore
    Shared --> RobotCfg
```

---

## 2. Architectural Layers

### 2.1 Application Bootstrap

Owned by `main/`. Identical to V1 with one additional responsibility: initialize
`hex_rs485_master` and start the RS485 communication task before entering the
locomotion loop.

### 2.2 Motion Stack

The motion stack is identical to V1 through `kpp_apply_limits`. The only change
is in `hex_actuation`.

Components:
- `hex_locomotion`: user command mapping, gait scheduling, swing target
  generation, whole-body control. Unchanged from V1.
- `hex_motion_limits`: KPP-based velocity, acceleration, and jerk limiting plus
  state estimation. Unchanged from V1.
- `hex_actuation`: converts limited joint commands to wire format and writes
  them to the shared command buffer. Returns immediately — no bus I/O, no
  blocking. Same public API as V1; V2 implementation swaps PWM register writes
  for command buffer writes.
- `hex_kinematics`: math-only leg kinematics primitives. Unchanged from V1.
- `hex_robot_config`: geometry, mount pose, joint calibration, and servo mapping
  consumption. Unchanged from V1.

Design intent:
- No component in the motion stack touches the RS485 bus or blocks on leg
  communication.
- `hex_actuation` keeps the same public API as V1 so the rest of the motion
  stack requires no changes.

### 2.3 RS485 Communication Stack

New in V2. Owns the physical RS485 bus and all leg communication.

Components:
- `hex_rs485_master`: dedicated FreeRTOS task; owns the RS485 bus exclusively;
  executes a per-leg send-and-poll cycle; writes results to the telemetry
  buffer.
- **Command buffer**: shared memory written by `hex_actuation` (main loop) and
  read by `hex_rs485_master` (comm task). Holds desired joint angles and arrival
  times for all six legs. The comm task always reads the latest written value;
  writes from the main loop are non-blocking.
- **Telemetry buffer**: shared memory written by `hex_rs485_master` (comm task)
  and read by motion stack consumers. Holds the latest available per-leg
  telemetry (per-servo current, leg status). May be up to one comm cycle stale.

Per-leg transaction (executed by `hex_rs485_master` for each leg in sequence):

```
1. Read desired angles for leg N from command buffer.
2. Assert DE high — transmit mode.
3. Send command frame to leg N (desired joint angles + arrival time).
4. Release DE low — receive mode.
5. Wait for telemetry response from leg N (per-servo current + leg status).
6. Write telemetry to buffer entry for leg N.
```

This repeats for legs 1 through 6, then immediately restarts. The telemetry
buffer entry for each leg is updated as soon as its transaction completes — the
main loop does not need to wait for all six legs before any result is available.

Design intent:
- The RS485 bus is owned exclusively by `hex_rs485_master`. No other component
  asserts DE or writes to the bus.
- Send and poll are a single transaction per leg so current measurements are as
  fresh as the bus cycle allows. This is the minimum possible latency for
  detecting leg touchdown from a current spike.
- A single leg timing out must not stall the comm cycle. `hex_rs485_master`
  applies a per-leg response timeout and moves on to leg N+1.
- The comm task rate is determined by per-leg transaction time (baud rate, frame
  sizes, DE turnaround, leg response latency) and is independent of the 100 Hz
  main loop rate.

### 2.4 Controller And Transport Stack

Identical to V1. See
[../interfaces/CONTROLLER_DRIVERS.md](../interfaces/CONTROLLER_DRIVERS.md).

### 2.5 RPC And Configuration Stack

Identical to V1. See
[../interfaces/RPC_SYSTEM_DESIGN.md](../interfaces/RPC_SYSTEM_DESIGN.md)
and
[../configuration/CONFIGURATION_PERSISTENCE_DESIGN.md](../configuration/CONFIGURATION_PERSISTENCE_DESIGN.md).

---

## 3. Runtime Flows

### 3.1 Boot Flow

1. Initialize configuration manager and make namespace state available.
2. Start RPC transport/core services.
3. Bring up Wi-Fi AP and transport-facing controller services as configured.
4. Initialize robot runtime modules that consume loaded configuration.
5. Initialize `hex_rs485_master` and start the RS485 communication task.
6. Enter the 100 Hz locomotion loop.

RS485 initialization must complete before the locomotion loop starts so that the
comm task is running and the command buffer is being serviced from the first
loop cycle.

### 3.2 100 Hz Locomotion Loop

The pipeline is structurally identical to V1:

```mermaid
flowchart TD
    Poll[user_command_poll]
    Sched[gait_scheduler_update]
    Swing[swing_trajectory_generate]
    Control[whole_body_control_compute]
    Limit[kpp_apply_limits]
    Execute[robot_execute]
    State[kpp_update_state]

    Poll --> Sched --> Swing --> Control --> Limit --> Execute --> State
```

`robot_execute` (inside `hex_actuation`) writes desired joint angles and arrival
times to the command buffer and returns. The call never blocks on bus I/O.

Telemetry from the latest completed comm cycle is available in the telemetry
buffer at any point in the loop. Locomotion stages that need ground contact
information (e.g. current-spike-based touchdown detection) read from this buffer
non-blocking.

### 3.3 RS485 Communication Task

`hex_rs485_master` runs as an independent FreeRTOS task:

```mermaid
flowchart TD
    Start[Begin leg cycle: N = 1]
    Read[Read command buffer for leg N]
    Send[Send command frame to leg N]
    Poll[Wait for telemetry from leg N\nwith timeout]
    Write[Write telemetry buffer for leg N]
    Next{N = 6?}
    Inc[N = N + 1]

    Start --> Read --> Send --> Poll --> Write --> Next
    Next -- no --> Inc --> Read
    Next -- yes --> Start
```

If a leg does not respond within its timeout window, its telemetry buffer entry
is marked stale and the cycle advances. The rest of the legs are unaffected.

### 3.4 Information Flow

```mermaid
flowchart LR
    ControllerState[Normalized controller state]
    UserCmd[user_command_t]
    SchedState[Scheduler state\nphase + support/swing]
    FootTargets[Body-frame foot targets]
    JointDesired[Desired joint command set]
    JointLimited[Limited joint command set]
    CmdBuf[[Command buffer\nangles + arrival times]]
    TelBuf[[Telemetry buffer\ncurrent + status per leg]]

    Core[hex_controller_core]
    Loc[hex_locomotion]
    Lim[hex_motion_limits]
    Act[hex_actuation]
    Kin[hex_kinematics]
    RobotCfg[hex_robot_config]
    CfgMgr[hex_config_manager]
    RS485M[hex_rs485_master]

    Core --> ControllerState --> Loc
    Loc --> UserCmd --> Loc
    Loc --> SchedState --> Loc
    Loc --> FootTargets

    RobotCfg --> Loc
    Kin --> Loc
    CfgMgr --> RobotCfg
    Loc --> JointDesired

    JointDesired --> Lim
    CfgMgr --> Lim
    RobotCfg --> Lim
    Lim --> JointLimited

    JointLimited --> Act
    RobotCfg --> Act
    Act --> CmdBuf

    CmdBuf --> RS485M --> TelBuf --> Loc
```

The telemetry buffer feeds back into `hex_locomotion` so that ground contact
events detected from current spikes can influence gait decisions in real time.

---

## 4. Component Ownership Summary

### Motion And Robot Behavior

- `hex_locomotion`: high-level motion intent to desired body/leg targets.
  Unchanged from V1; reads telemetry buffer for ground contact data.
- `hex_motion_limits`: dynamic command conditioning and state estimation.
  Unchanged from V1.
- `hex_actuation`: writes joint commands to the shared command buffer.
  Same public API as V1; no PWM peripheral access in V2.
- `hex_kinematics`: reusable leg math. Unchanged from V1.
- `hex_robot_config`: geometry, mounts, calibration, and servo map projection.
  Unchanged from V1.

### RS485 Communication

- `hex_rs485_master`: exclusive RS485 bus owner; dedicated FreeRTOS task;
  per-leg send-and-poll cycle; writes telemetry buffer; handles per-leg
  timeouts.

### Input, Transport, And Control

Identical to V1. See [../interfaces/CONTROLLER_DRIVERS.md](../interfaces/CONTROLLER_DRIVERS.md).

### RPC, Configuration, And Shared Contracts

Identical to V1. See [../interfaces/RPC_SYSTEM_DESIGN.md](../interfaces/RPC_SYSTEM_DESIGN.md) and
[../configuration/CONFIGURATION_PERSISTENCE_DESIGN.md](../configuration/CONFIGURATION_PERSISTENCE_DESIGN.md).

---

## 5. Dependency Rules

Rules inherited from V1:
- Motion components must not depend on transport-specific controller drivers.
- Transport drivers must not call locomotion modules directly.
- Kinematics code must remain usable without hardware dependencies.
- RPC command handling must rely on public controller/config APIs rather than
  internal transport details.

Additional V2 rules:
- **The 100 Hz locomotion loop must never block on leg communication.**
  `hex_actuation` writes to the command buffer and returns immediately. No
  motion stack component reads from or writes to the RS485 bus directly.
- **The RS485 bus is owned exclusively by `hex_rs485_master`.** No other
  component asserts DE, reads from, or writes to the RS485 UART peripheral.
- **Telemetry consumers must tolerate stale data.** The telemetry buffer holds
  the latest available result per leg; a consumer must not assume the entry was
  updated in the current loop cycle.
- **A single leg timing out must not stall the comm cycle.**
  `hex_rs485_master` applies a per-leg response timeout and advances to the
  next leg unconditionally.

---

## 6. Configuration Architecture Position

Identical to V1. Configuration is part of the runtime contract, not an
auxiliary subsystem. See
[../configuration/CONFIGURATION_PERSISTENCE_DESIGN.md](../configuration/CONFIGURATION_PERSISTENCE_DESIGN.md).

---

## 7. Documentation Map

- Hardware topology and board responsibilities: [HARDWARE_AND_MECHANICS.md](HARDWARE_AND_MECHANICS.md)
- RS485 protocol — packet format, framing, addressing, timing: [../interfaces/RS485_PROTOCOL.md](../interfaces/RS485_PROTOCOL.md) *(to be written)*
- LegBoard RP2040 firmware architecture: [../../firmware/leg/](../../firmware/leg/) *(to be written)*
- Configuration model: [../configuration/CONFIGURATION_PERSISTENCE_DESIGN.md](../configuration/CONFIGURATION_PERSISTENCE_DESIGN.md)
- RPC guide: [../interfaces/RPC_USER_GUIDE.md](../interfaces/RPC_USER_GUIDE.md)
- Hardware schematics: [../../hardware/README.md](../../hardware/README.md)

---

## 8. What This Document Does Not Cover

- Hardware board descriptions, power topology, and connector pinouts — see
  [HARDWARE_AND_MECHANICS.md](HARDWARE_AND_MECHANICS.md).
- RS485 packet format, framing, leg addressing, and timing budget — see
  [../interfaces/RS485_PROTOCOL.md](../interfaces/RS485_PROTOCOL.md).
- LegBoard (RP2040) firmware: interpolation model, watchdog behavior, PWM
  generation — see [`firmware/leg/`](../../firmware/leg/).
- Per-parameter configuration tables and namespace definitions — see common
  configuration docs.
- Forward-looking plans and feature backlog — see
  [../plans/TODO.md](../plans/TODO.md).

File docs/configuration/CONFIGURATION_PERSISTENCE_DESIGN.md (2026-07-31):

# Hexapod Configuration Persistence Design

## Overview

This document outlines the design decisions for the hexapod robot's configuration persistence layer, including storage method selection, RPC architecture, and migration strategy.

## Storage Method Selection

### Requirements Analysis

**Must Have:**
- Fast read access for real-time parameter updates
- Easy development and debugging
- Access via RPC for read/write operations  
- Space for 200+ configuration values
- Live parameter updates with immediate robot response

**Nice to Have:**
- Dead easy development workflow
- Filesystem-like access with named parameters
- Parameter segregation/organization (namespaces)

### Storage Options Evaluated

#### 1. NVS (Non-Volatile Storage) ✅ **CHOSEN**

**Advantages:**
- **Optimal for key-value configuration data** - designed exactly for this use case
- **Fast random access** - O(1) key lookups with minimal overhead
- **Built-in namespace support** - perfect for parameter organization
- **Automatic wear leveling** and power-loss protection
- **Simple API** - `nvs_set_*()` and `nvs_get_*()` functions
- **Type safety** - built-in support for int8, int16, int32, float, string, blob
- **Perfect for RPC** - keys are strings, ideal for API endpoints
- **Atomic operations** - transactional safety
- **Minimal overhead** - efficient storage with small per-parameter cost

**Storage Requirements:**
- 200+ config values ≈ 10-20KB total
- Recommended 64KB NVS partition (allows growth + wear leveling)

#### 2. FAT Filesystem ❌ **REJECTED**

**Disadvantages:**
- **Slow access** - file open/read/parse overhead for each parameter
- **Complex development** - file management, parsing, serialization required
- **Write amplification** - changing one parameter requires rewriting entire file
- **No built-in wear leveling** for small frequent writes
- **Corruption prone** on power loss during writes
- **Overkill** for configuration data
- **Poor RPC performance** - would require file parsing for each parameter access

#### 3. SPIFFS/LittleFS ❌ **NOT SUITABLE**

**Why Not Considered:**
- **SPIFFS**: Deprecated in ESP-IDF, wear leveling issues, slower than NVS for key-value access
- **LittleFS**: Better than SPIFFS but still filesystem overhead, designed for file storage not configuration
- **Both suffer from**: File-based access overhead, complex parameter management, no built-in key-value semantics

### NVS Namespace Organization

Following Betaflight's Parameter Group (PG) concept, organized by logical functionality:

```c
// Primary namespace string names (console/RPC friendly)
"joint_cal"   // Joint calibration per leg/joint
"leg_geom"    // Leg link lengths and mounting poses
"motion_lim"  // KPP velocity/acceleration/jerk limits
"servo_map"   // GPIO pins and driver selections
"controller"  // Controller driver configurations
"gait"        // Gait scheduler and trajectory parameters
"system"      // System-wide settings and safety
"debug"       // Debug and logging parameters
"wifi"        // WiFi AP and network configuration
```

## Detailed Namespace Design

### 1. joint_cal - Joint Calibration Data
**Derived from:** `robot_config_t.joint_calib[NUM_LEGS][3]`

**Scope and parameter count:**

- 6 legs × 3 joints per leg (coxa, femur, tibia)
- 7 parameters per joint
- Total: 126 parameters in `joint_cal`

**Parameter pattern:**

- Canonical form: `leg{0-5}_{coxa|femur|tibia}_{suffix}`
- Supported joint aliases in parser: `coxa|c`, `femur|f`, `tibia|t`
- Parameter discovery (`list joint_cal`) emits canonical full joint names

**Supported suffixes and constraints:**

- `offset` (float, radians): range `[-6.28, 6.28]`
- `invert` (int32): allowed values `-1` or `1`
- `min` (float, radians): range `[-6.28, 6.28]`
- `max` (float, radians): range `[-6.28, 6.28]`
- `pwm_min` (int32, us): range `[500, 3000]`
- `pwm_max` (int32, us): range `[500, 3000]`
- `neutral` (int32, us): range `[500, 3000]`

**Examples:**

- `leg0_coxa_offset`
- `leg2_femur_invert`
- `leg5_tibia_pwm_min`
- `leg1_c_neutral` (accepted by parser alias, canonical listing remains `leg1_coxa_neutral`)

**Naming to struct mapping:**
```c
// Joint calibration parameters (7 per joint × 3 joints × 6 legs = 126 total)
"leg{0-5}_coxa_offset"      // joint_calib_t.zero_offset_rad
"leg{0-5}_coxa_invert"      // joint_calib_t.invert_sign  
"leg{0-5}_coxa_min"         // joint_calib_t.min_rad
"leg{0-5}_coxa_max"         // joint_calib_t.max_rad
"leg{0-5}_coxa_pwm_min"     // joint_calib_t.pwm_min_us
"leg{0-5}_coxa_pwm_max"     // joint_calib_t.pwm_max_us
"leg{0-5}_coxa_neutral"     // joint_calib_t.neutral_us

// Same pattern for femur and tibia joints
"leg{0-5}_femur_offset", "leg{0-5}_femur_invert", etc.
"leg{0-5}_tibia_offset", "leg{0-5}_tibia_invert", etc.
```

**Persistence key shape in NVS (internal):**

- Offset: `l{leg}_{c|f|t}_off`
- Invert: `l{leg}_{c|f|t}_inv`
- Min/Max: `l{leg}_{c|f|t}_min`, `l{leg}_{c|f|t}_max`
- PWM: `l{leg}_{c|f|t}_pmin`, `l{leg}_{c|f|t}_pmax`, `l{leg}_{c|f|t}_neut`

### 2. leg_geom - Leg Physical Properties  
**Derived from:** `leg_geometry_t` and mounting poses

**Scope and parameter count:**

- 6 legs
- 9 float parameters per leg
- Total: 54 parameters in `leg_geom`

**Parameter pattern:**

- Canonical form: `leg{0-5}_{suffix}`
- Supported suffixes:
  - `len_coxa`, `len_femur`, `len_tibia`
  - `mount_x`, `mount_y`, `mount_z`, `mount_yaw`
  - `stance_out`, `stance_fwd`

**Validation constraints (from descriptor metadata):**

- Link lengths: `[0.01, 1.00]` meters
- Mount yaw: `[-6.2831853, 6.2831853]` radians
- Mount XYZ and stance values: `[-1.0, 1.0]` meters

**Examples:**

- `leg0_len_coxa`
- `leg0_mount_yaw`
- `leg3_stance_out`

**Naming to struct mapping:**
```c
// Mechanical dimensions (3 per leg)
"leg{0-5}_len_coxa"         // leg_geometry_t.len_coxa (meters)
"leg{0-5}_len_femur"        // leg_geometry_t.len_femur (meters)  
"leg{0-5}_len_tibia"        // leg_geometry_t.len_tibia (meters)

// Mounting poses in body frame (4 per leg)
"leg{0-5}_mount_x"          // Base pose X offset (meters)
"leg{0-5}_mount_y"          // Base pose Y offset (meters)
"leg{0-5}_mount_z"          // Base pose Z offset (meters)  
"leg{0-5}_mount_yaw"        // Base pose yaw rotation (radians)

// Stance positions in leg-local frame (2 per leg)
"leg{0-5}_stance_out"       // Outward stance distance (meters)
"leg{0-5}_stance_fwd"       // Forward stance distance (meters)
```

**Persistence key shape in NVS (internal):**

- `len_coxa`: `l{leg}_lc`
- `len_femur`: `l{leg}_lf`
- `len_tibia`: `l{leg}_lt`
- `mount_x`: `l{leg}_mx`
- `mount_y`: `l{leg}_my`
- `mount_z`: `l{leg}_mz`
- `mount_yaw`: `l{leg}_myaw`
- `stance_out`: `l{leg}_so`
- `stance_fwd`: `l{leg}_sf`

### 3. motion_lim - KPP Motion Parameters
**Derived from:** `kpp_config.h` motion limits and filters

**Scope and parameter count:**

- Flat namespace (not per-leg)
- 25 float parameters in `motion_lim`

**Parameter groups:**

- Joint limit vectors (coxa/femur/tibia):
  - `max_velocity_*`, `max_acceleration_*`, `max_jerk_*`
- Estimation filters:
  - `velocity_filter_alpha`, `accel_filter_alpha`, `leg_velocity_filter_alpha`
  - `body_velocity_filter_alpha`, `body_pitch_filter_alpha`, `body_roll_filter_alpha`
- Geometric/validation parameters:
  - `front_to_back_distance`, `left_to_right_distance`
  - `max_leg_velocity`, `max_body_velocity`, `max_angular_velocity`
  - `min_dt`, `max_dt`
- Body frame offsets:
  - `body_offset_x`, `body_offset_y`, `body_offset_z`

**Validation constraints (descriptor):**

- `max_velocity_*`: `[0.0, 20.0]`
- `max_acceleration_*`: `[0.0, 5000.0]`
- `max_jerk_*`: `[0.0, 50000.0]`
- Filter alphas: `[0.0, 1.0]`
- `front_to_back_distance`, `left_to_right_distance`: `[0.0, 2.0]`
- `max_leg_velocity`: `[0.0, 20.0]`
- `max_body_velocity`: `[0.0, 10.0]`
- `max_angular_velocity`: `[0.0, 20.0]`
- `min_dt`, `max_dt`: `[0.0001, 1.0]`
  - Additional relation: `min_dt <= max_dt`
- `body_offset_x/y/z`: `[-1.0, 1.0]`

**Implemented parameter names:**
```c
// Joint motion limits (9 total)
"max_velocity_coxa"         // KPP_MAX_VELOCITY_COXA (rad/s)
"max_velocity_femur"        // KPP_MAX_VELOCITY_FEMUR (rad/s)
"max_velocity_tibia"        // KPP_MAX_VELOCITY_TIBIA (rad/s)
"max_acceleration_coxa"     // KPP_MAX_ACCELERATION_COXA (rad/s²)
"max_acceleration_femur"    // KPP_MAX_ACCELERATION_FEMUR (rad/s²) 
"max_acceleration_tibia"    // KPP_MAX_ACCELERATION_TIBIA (rad/s²)
"max_jerk_coxa"            // KPP_MAX_JERK_COXA (rad/s³)
"max_jerk_femur"           // KPP_MAX_JERK_FEMUR (rad/s³)
"max_jerk_tibia"           // KPP_MAX_JERK_TIBIA (rad/s³)

// State estimation filters (6 total)
"velocity_filter_alpha"     // KPP_VELOCITY_FILTER_ALPHA
"accel_filter_alpha"        // KPP_ACCEL_FILTER_ALPHA
"leg_velocity_filter_alpha" // KPP_LEG_VELOCITY_FILTER_ALPHA
"body_velocity_filter_alpha"// KPP_BODY_VELOCITY_FILTER_ALPHA
"body_pitch_filter_alpha"   // KPP_BODY_PITCH_FILTER_ALPHA
"body_roll_filter_alpha"    // KPP_BODY_ROLL_FILTER_ALPHA

// Geometric and validation parameters (7 total)
"front_to_back_distance"    // KPP_FRONT_TO_BACK_DISTANCE (meters)
"left_to_right_distance"    // KPP_LEFT_TO_RIGHT_DISTANCE (meters)
"max_leg_velocity"          // KPP_MAX_LEG_VELOCITY (m/s)
"max_body_velocity"         // KPP_MAX_BODY_VELOCITY (m/s) 
"max_angular_velocity"      // KPP_MAX_ANGULAR_VELOCITY (rad/s)
"min_dt"                    // KPP_MIN_DT (seconds)
"max_dt"                    // KPP_MAX_DT (seconds)

// Body frame offsets
"body_offset_x"             // KPP_BODY_OFFSET_X (meters)
"body_offset_y"             // KPP_BODY_OFFSET_Y (meters)
"body_offset_z"             // KPP_BODY_OFFSET_Z (meters)
```

**Persistence key shape in NVS (internal):**

- Joint vectors: `mv_{c|f|t}`, `ma_{c|f|t}`, `mj_{c|f|t}`
- Filters: `vf_a`, `af_a`, `lvf_a`, `bvf_a`, `bp_a`, `br_a`
- Geometry/limits: `fb_d`, `lr_d`, `ml_v`, `mb_v`, `ma_v`, `min_dt`, `max_dt`
- Body offsets: `bo_x`, `bo_y`, `bo_z`

**Runtime consumption contract (implemented):**

- `hex_motion_limits` (`kpp_system`) loads `motion_lim` from `config_manager` during `kpp_init`.
- No hardcoded fallback is used for completed runtime integration.
- If `config_manager` is not initialized, `motion_lim` is not loaded, or config values are invalid, `kpp_init` fails fast and logs an error.
- `motion_lim` is therefore a required runtime dependency for KPP startup, not an optional tuning source.

### 4. servo_map - Hardware Configuration
**Derived from:** `robot_config_t` servo and MCPWM mappings

**Servo hardware mapping:**
```c
// GPIO pin assignments (18 parameters per leg × 6 legs = 108 total)
"leg{0-5}_coxa_gpio"        // servo_gpio[leg][LEG_SERVO_COXA] 
"leg{0-5}_femur_gpio"       // servo_gpio[leg][LEG_SERVO_FEMUR]
"leg{0-5}_tibia_gpio"       // servo_gpio[leg][LEG_SERVO_TIBIA]

// Driver selection (18 parameters per leg × 6 legs = 108 total)
"leg{0-5}_coxa_driver"      // servo_driver_sel[leg][LEG_SERVO_COXA] (0=MCPWM, 1=LEDC)
"leg{0-5}_femur_driver"     // servo_driver_sel[leg][LEG_SERVO_FEMUR]
"leg{0-5}_tibia_driver"     // servo_driver_sel[leg][LEG_SERVO_TIBIA]

// MCPWM group assignment (6 parameters)
"leg{0-5}_mcpwm_group"      // mcpwm_group_id[leg]
```

### 5. controller - Input Device Configuration
**Derived from:** `controller_config_t` and driver-specific configs

**Controller driver configuration:**
```c
// Core controller settings (~8 parameters)
"driver_type"               // controller_driver_type_e
"task_stack"               // task_stack (bytes)
"task_priority"            // task_prio

// FlySky iBUS driver settings (~6 parameters)
"flysky_uart_port"         // controller_flysky_ibus_cfg_t.uart_port
"flysky_tx_gpio"           // controller_flysky_ibus_cfg_t.tx_gpio
"flysky_rx_gpio"           // controller_flysky_ibus_cfg_t.rx_gpio
"flysky_rts_gpio"          // controller_flysky_ibus_cfg_t.rts_gpio
"flysky_cts_gpio"          // controller_flysky_ibus_cfg_t.cts_gpio
"flysky_baud_rate"         // controller_flysky_ibus_cfg_t.baud_rate

// Channel mapping and calibration (~20 parameters)
"channel_deadzone"         // Dead zone for stick inputs
"channel_expo"             // Exponential curve factor
"stick_calibration_min"    // Minimum stick values per channel
"stick_calibration_max"    // Maximum stick values per channel
"switch_thresholds"        // 3-position switch thresholds
```

### 6. gait - Locomotion Parameters  
**Derived from:** `gait_scheduler_t` and `swing_trajectory_t`

**Gait and trajectory parameters:**
```c
// Gait timing (~8 parameters)
"cycle_time"               // gait_scheduler_t.cycle_time (seconds)
"default_gait_mode"        // Default gait type (tripod/wave/ripple)

// Swing trajectory parameters (~12 parameters)
"step_length"              // swing_trajectory_t.step_length (meters)
"clearance_height"         // swing_trajectory_t.clearance_height (meters)
"y_range_m"                // swing_trajectory_t.y_range_m (meters)
"z_min_m"                  // swing_trajectory_t.z_min_m (meters)
"z_max_m"                  // swing_trajectory_t.z_max_m (meters)

// Future gait parameters (noted in TODOs)
"max_turn_angle"           // Maximum turn angle (radians)
"turn_direction"           // Turn direction preference
"step_height_scale"        // Dynamic step height scaling
"stance_width_scale"       // Dynamic stance width scaling
```

### 7. system - System-Wide Settings
**Derived from:** System safety and operational parameters

**System configuration:**
```c
// Safety settings (~10 parameters)
"emergency_stop_enabled"    // Emergency stop functionality
"auto_disarm_timeout"       // Auto-disarm timeout (seconds)
"safety_voltage_min"        // Minimum battery voltage (volts)
"temperature_limit_max"     // Maximum operating temperature (°C)
"motion_timeout_ms"         // Motion command timeout
"startup_delay_ms"          // Startup safety delay
"max_control_frequency"     // Maximum control loop frequency (Hz)

// System identification
"robot_id"                  // Unique robot identifier
"robot_name"                // Human-readable robot name
"config_version"            // Configuration schema version
```

### 8. debug - Development and Diagnostic Settings
**Derived from:** `kpp_config.h` compile-time logging toggles

**Debug and logging configuration:**
```c
// Logging settings
"enable_state_logging"      // KPP_ENABLE_STATE_LOGGING
"log_interval"              // KPP_LOG_INTERVAL (control cycles)
"enable_limit_logging"      // KPP_ENABLE_LIMIT_LOGGING
```

```c
// Future runtime logging namespace candidates
"log_level"                 // ESP log level (ERROR/WARN/INFO/DEBUG)
"telemetry_rate"            // Telemetry broadcast rate (Hz)
"enable_performance_stats"  // Performance monitoring enable
```

### 9. wifi - Network Configuration
**Derived from:** `wifi_ap_options_t` and future network settings

**WiFi and network parameters:**
```c
// WiFi AP settings (~10 parameters)
"ap_ssid_mode"             // wifi_ap_ssid_mode_e
"ap_fixed_prefix"          // SSID prefix for MAC/random modes
"ap_fixed_ssid"            // Fixed SSID when mode == FIXED
"ap_password"              // WPA2 password (or NULL for open)
"ap_channel"               // WiFi channel (1-13)
"ap_max_clients"           // Maximum concurrent clients

// Network services (~8 parameters)
"web_server_port"          // HTTP server port (default 80)
"websocket_port"           // WebSocket server port  
"telemetry_port"           // UDP telemetry port
"api_rate_limit"           // API request rate limit (req/sec)
"enable_ota_updates"       // Over-the-air update capability
"mdns_hostname"            // mDNS hostname (hexapod.local)
```

## Summary Statistics

**Total Estimated Parameters:** ~600-700 parameters
- Joint Calibration: ~126 parameters (18 × 6 legs + extras)
- Leg Geometry: 54 parameters (9 × 6 legs)
- Motion Limits: 25 parameters
- Servo Mapping: ~114 parameters (19 × 6 legs)
- Controller: ~35 parameters
- Gait: ~20 parameters
- System: ~15 parameters
- Debug: ~18 parameters
- WiFi: ~18 parameters

**Storage Requirements:** ~35-50KB for all parameters (well within 64KB NVS partition)

## RPC Architecture (Draft)

### Dual Method Approach

**Simplified design without transaction complexity:**

```c
// Memory-only operations (immediate effect, no persistence)
esp_err_t config_set_joint_offset_memory(int leg_index, leg_servo_t joint, float offset_rad);
esp_err_t config_set_motion_limit_memory(leg_servo_t joint, float max_velocity);

// Persistent operations (immediate effect + save to NVS)  
esp_err_t config_set_joint_offset_persist(int leg_index, leg_servo_t joint, float offset_rad);
esp_err_t config_set_motion_limit_persist(leg_servo_t joint, float max_velocity);

// Batch operations (best of both worlds)
esp_err_t config_save_namespace(config_namespace_t ns);     // Save all memory changes
esp_err_t config_reload_namespace(config_namespace_t ns);   // Discard changes, reload from NVS
```

### RPC Protocol Design

**JSON-based RPC for configurator portal:**

```json
// Live tuning - immediate visual feedback, no flash wear
{
  "cmd": "set_joint_offset_memory",
  "leg": 0,
  "joint": "coxa", 
  "value": 0.523
}

// User likes the result, saves it permanently
{
  "cmd": "set_joint_offset_persist", 
  "leg": 0,
  "joint": "coxa",
  "value": 0.523
}

// Batch save multiple changes at once
{
  "cmd": "save_namespace",
  "namespace": "joint_cal"
}

// Revert all unsaved changes
{
  "cmd": "reload_namespace", 
  "namespace": "joint_cal"
}
```

### RPC-to-NVS Integration

**Generic parameter access for configurator discovery:**

```c
// RPC commands map directly to NVS operations
esp_err_t config_get_parameter_float(const char *namespace_str, const char *key, float *value);
esp_err_t config_set_parameter_float(const char *namespace_str, const char *key, float value);

// Example RPC endpoints:
// GET  /api/config/joint_cal/leg0_coxa_offset
// PUT  /api/config/joint_cal/leg0_coxa_offset  {"value": 0.523, "persist": false}
// POST /api/config/joint_cal/save
// POST /api/config/joint_cal/reload
```

**Configuration state management:**
```c
typedef struct {
    bool namespace_dirty[CONFIG_NS_COUNT];   // Which namespaces have unsaved changes
    bool namespace_loaded[CONFIG_NS_COUNT];  // Which namespaces are in memory cache
} config_simple_state_t;
```

### Configurator Workflows

**Live Tuning Workflow:**
1. User slides joint offset → `set_joint_offset_memory()` → robot moves immediately  
2. User continues adjusting → more `_memory()` calls → immediate feedback
3. User likes result → `save_namespace("joint_cal")` → persisted to NVS
4. OR user doesn't like it → `reload_namespace("joint_cal")` → back to saved state

**Cautious Workflow:**  
1. User changes value → `set_joint_offset_persist()` → immediate save to NVS
2. Each change is automatically safe

**Batch Workflow:**
1. User makes multiple memory changes  
2. Tests robot behavior with all changes
3. Either saves all (`save_namespace`) or reloads all (`reload_namespace`)

## Configuration Migration Strategy

### Sequential In-Firmware Migration

**Database-style migration approach:**

```c
#define CURRENT_CONFIG_VERSION 5

const migration_step_t migrations[] = {
    {.from = 1, .to = 2, .migrate_fn = migrate_v1_to_v2},
    {.from = 2, .to = 3, .migrate_fn = migrate_v2_to_v3},
    {.from = 3, .to = 4, .migrate_fn = migrate_v3_to_v4}, 
    {.from = 4, .to = 5, .migrate_fn = migrate_v4_to_v5},
};

esp_err_t config_manager_migrate(uint16_t detected_version) {
    for (int i = 0; i < ARRAY_SIZE(migrations); i++) {
        if (migrations[i].from == detected_version) {
            ESP_ERROR_CHECK(migrations[i].migrate_fn());
            detected_version = migrations[i].to;
            config_save_version(detected_version);  // Save intermediate state
        }
    }
    return ESP_OK;
}
```

**Migration Safety Features:**
- **Automatic backup** before migration starts
- **Rollback capability** if migration fails  
- **Intermediate state saving** to handle power loss during migration
- **Validation** after each migration step

### Backup/Restore System

**Versioned JSON export/import:**

```json
{
  "metadata": {
    "version": 5,
    "firmware": "1.2.3",
    "timestamp": 1699200000,
    "robot_id": "hexapod_001"
  },
  "joint_cal": {
    "leg0_coxa_offset": 0.523,
    "leg0_coxa_min": -1.57,
    "leg0_coxa_max": 1.57
  },
  "motion_limits": {
    "kpp_max_vel_coxa": 5.0,
    "kpp_max_accel_coxa": 600.0
  }
}
```

**External Backup Migration:**
- Python script mirrors firmware migration logic
- Enables backup migration without robot hardware
- Slight code duplication but worth it for robustness

## Advantages Over Betaflight's Approach

### Betaflight Configuration Limitations:
- **Bulk operations only** - saves entire parameter groups as binary blobs
- **No individual parameter access** - cannot change single values efficiently  
- **Flash sector management** - complex wear leveling and corruption risks
- **CLI/MSP bottleneck** - configurator must read/modify/write entire groups

### Hexapod Configuration Advantages:
- **Individual parameter persistence** - instant single-value saves via NVS
- **Live parameter updates** - immediate robot response during tuning
- **Selective persistence** - memory vs permanent storage choice
- **Much more responsive** configurator experience
- **Automatic wear leveling** handled by ESP-IDF NVS layer
- **Simple key-value model** - easier debugging and development

## Implementation Status

### Phase 1: Core Infrastructure ✅ **COMPLETED**
1. **NVS namespace setup** and basic parameter storage - ✅ Done
2. **Memory cache system** for live parameter updates - ✅ Done  
3. **Dual method API** (memory vs persist functions) - ✅ Done
4. **Integration with existing robot_config.h** structures - ✅ Done

#### Implementation Notes:
- **Files created:** `config_manager.h`, `config_manager.c`, `config_test.c`
- **System namespace is implemented and wired** for core parameters (ongoing expansion expected)
- **joint_cal namespace is implemented and wired** (defaults, load/save, parameter discovery, typed get/set)
- **leg_geom namespace is implemented and wired** (defaults, load/save, parameter discovery, typed float get/set)
- **motion_lim namespace is implemented and wired** (defaults, load/save, parameter discovery, typed float get/set)
- **controller namespace is implemented and wired** (defaults, load/save, parameter discovery, typed int/uint get/set)
- **wifi namespace is implemented and wired** (defaults, load/save, parameter discovery, typed uint/string get/set)
- **KPP runtime now consumes `motion_lim` at startup** and fails fast if required configuration is unavailable/invalid.
- **NVS operations** working with automatic error handling and wear leveling
- **Dual-method API** demonstrated: `config_set_*_memory()` vs `config_set_*_persist()`
- **Generic parameter API** foundation created for RPC integration
- **Factory reset** and migration infrastructure in place

### System Configuration Parameters (Implemented):
```c
typedef struct {
    // Safety settings
    bool emergency_stop_enabled;        // Emergency stop functionality
    uint32_t auto_disarm_timeout;       // Auto-disarm timeout (seconds) 
    float safety_voltage_min;           // Minimum battery voltage (volts)
    float temperature_limit_max;        // Maximum operating temperature (°C)
    uint32_t motion_timeout_ms;         // Motion command timeout
    uint32_t startup_delay_ms;          // Startup safety delay
    uint32_t max_control_frequency;     // Maximum control loop frequency (Hz)
    
    // System identification  
    char robot_id[32];                  // Unique robot identifier (from MAC)
    char robot_name[64];                // Human-readable robot name
    uint16_t config_version;            // Configuration schema version
} system_config_t;
```

### Usage Examples:
```c
// Initialize configuration system
config_manager_init();

// Get current configuration
const system_config_t* config = config_get_system();

// Live tuning (immediate effect, no flash write)
config_set_safety_voltage_min_memory(6.8f);
config_set_robot_name_memory("Test Robot");

// Check for unsaved changes
if (config_manager_has_dirty_data()) {
    // Save all changes at once
  config_manager_save_namespace_by_name("system");
}

// Or save immediately (live tuning + persistence)  
config_set_safety_voltage_min_persist(7.0f);

```

## Implementation Plan (Updated)

### Phase 1: Core Infrastructure ✅ **COMPLETED**

### Phase 2: RPC Layer
1. **JSON-based parameter API** over WebSocket/HTTP
2. **Generic parameter access** functions  
3. **Namespace save/reload** operations
4. **Configuration state management**

### Phase 3: Migration System  
1. **Version detection** and sequential migration framework
2. **Migration safety features** (backup/rollback)
3. **JSON export/import** system  
4. **External migration tools**

### Phase 4: Configurator Integration
1. **Web-based configurator portal** using RPC API
2. **Live parameter tuning** with immediate robot feedback
3. **Configuration backup/restore** functionality  
4. **Bulk configuration management** for multiple robots

## Summary

The NVS-based approach provides the optimal foundation for the hexapod's configuration system, offering superior performance for live parameter tuning while maintaining simplicity and robustness. The dual-method RPC design enables flexible configurator workflows, and the migration system ensures smooth firmware updates throughout development.

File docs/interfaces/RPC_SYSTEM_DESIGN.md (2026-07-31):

# Hexapod RPC System Design

## Overview

This document outlines the design for a Remote Procedure Call (RPC) system for the hexapod robot, inspired by Betaflight's MSP (MultiWii Serial Protocol) and CLI systems. The RPC system will provide real-time parameter tuning, robot control, and debugging capabilities.

Normative scope:
- This file is the canonical RPC command contract.
- If other documentation conflicts with this file, this file takes precedence.

## Implementation Reality Check (2026-05)

The following items are confirmed in source code:

- Implemented transports:
    - Bluetooth Classic SPP via `hex_controller_driver_bt_classic`
    - WiFi TCP via `hex_controller_driver_wifi_tcp`
- Transport abstraction and routing:
    - Queue-based RX/TX transport layer in `hex_rpc_transport`
    - Transport-tagged responses routed back through the active transport in `rpc_commands.c`
- Defined but not yet implemented transport endpoint:
    - `RPC_TRANSPORT_SERIAL` enum exists, but no serial transport driver is currently wired.
- Implemented config namespaces visible through RPC `list namespaces`:
    - `system`, `joint_cal`, `leg_geom`, `motion_lim`, `controller`, `wifi`

## Goals

1. **✅ Multi-transport implementation (current)**: Bluetooth Classic and WiFi TCP implemented with abstraction layer
2. **✅ Task-based operation**: Queue-based RPC processing with dedicated tasks on Core 1  
3. **✅ Betaflight-inspired commands**: Simple, text-based commands for ease of use
4. **✅ Configuration integration**: Seamless integration with the hybrid configuration system
5. **🔲 Robot control**: Direct joint and leg control for testing and debugging (planned)
6. **✅ Performance**: Bulk operations for efficient data transfer
7. **✅ Transport extensibility**: Full abstraction layer implemented for easy transport addition

## Architecture Overview (Current Implementation: Multi-Transport Queue-Based)

```
┌─────────────────────────────────────────────────────────────────┐
│                    RPC System (Core 1)                         │
├─────────────────────────────────────────────────────────────────┤
│  ┌─────────────────┐  ┌─────────────────┐  ┌─────────────────┐ │
│  │   Bluetooth     │  │   WiFi TCP      │  │   Serial UART   │ │
│  │   Classic SPP   │  │   Transport     │  │   (Future)      │ │
│  └─────────────────┘  └─────────────────┘  └─────────────────┘ │
│           │                     │                     │         │
│  ┌─────────────────────────────────────────────────────────────┐ │
│  │              Transport Abstraction Layer                   │ │
│  │  ┌─────────────┐     ┌─────────────┐     ┌─────────────┐  │ │
│  │  │  RX Queue   │────▶│ RPC Process │────▶│  TX Queue   │  │ │
│  │  │             │     │    Task     │     │             │  │ │
│  │  └─────────────┘     └─────────────┘     └─────────────┘  │ │
│  └─────────────────────────────────────────────────────────────┘ │
│           │                                                     │
│  ┌─────────────────────────────────────────────────────────────┐ │
│  │                Command Parser & Dispatcher                  │ │
│  └─────────────────────────────────────────────────────────────┘ │
│           │                                                     │
│  ┌────────────────────┬────────────────────┬───────────────────┐ │
│  │   Config Commands  │  Control Commands  │  System Commands  │ │
│  └────────────────────┴────────────────────┴───────────────────┘ │
│                                │                                 │
│  ┌─────────────────┐  ┌─────────────────┐  ┌─────────────────┐ │
│  │ Configuration   │  │ Robot Control   │  │ System Status   │ │
│  │ Manager         │  │ (Legs/Joints)   │  │ & Diagnostics   │ │
│  └─────────────────┘  └─────────────────┘  └─────────────────┘ │
└─────────────────────────────────────────────────────────────────┘
```

## Transport Layer Design (✅ Implemented: Queue-Based Abstraction)

### 1. ✅ Transport Abstraction Layer (Implemented)

```c
// Current implementation - Queue-based transport abstraction
typedef enum {
    RPC_TRANSPORT_BLUETOOTH = 0,
    RPC_TRANSPORT_WIFI_TCP,
    RPC_TRANSPORT_SERIAL,
    RPC_TRANSPORT_INTERNAL,
    RPC_TRANSPORT_COUNT
} rpc_transport_type_t;

// Message structures for queue-based communication
typedef struct {
    rpc_transport_type_t transport;
    uint8_t data[256];
    size_t len;
} rpc_rx_message_t;

typedef struct {
    rpc_transport_type_t transport;
    char data[256];
    size_t len;
} rpc_tx_message_t;

// Transport registration and queue management
esp_err_t rpc_transport_init(void);
esp_err_t rpc_transport_rx_send(rpc_transport_type_t transport, const uint8_t* data, size_t len);
esp_err_t rpc_transport_tx_send(rpc_transport_type_t transport, const char* data, size_t len);
esp_err_t rpc_transport_register_sender(rpc_transport_type_t transport, rpc_transport_send_fn_t send_fn);
```

### 2. ✅ Bluetooth Classic Integration (Implemented)

- **Protocol**: Bluetooth Serial Port Profile (SPP) 
- **Device Name**: "HEXAPOD_XXXXXX" (MAC-derived suffix)
- **PIN**: Configurable (default: 1234)
- **Integration**: Queue-based RX/TX via transport abstraction
- **RPC Only**: The transport no longer distinguishes between binary and text frames. All data is treated as potential RPC commands.

### 3. ✅ WiFi TCP Integration (Implemented)

- **Protocol**: TCP server on configurable port (default: 5555)
- **Connection**: Single client connection per transport
- **Integration**: Queue-based RX/TX via transport abstraction  
- **RPC Only**: The transport no longer distinguishes between binary and text frames. All data is treated as potential RPC commands.

### 4. 🔲 Serial UART (Planned)

- **Protocol**: Standard UART (115200 baud default)
- **Integration target**: Will use same queue-based transport abstraction
- **Current code state**: enum and abstraction support exist; no serial RPC transport driver is registered yet

## Command Protocol Design

## Canonical Command Contract (P0)

This section defines the contract that clients should implement against.

### Contract Version

- Contract version: `rpc-text-v1`
- Encoding: ASCII/UTF-8 text
- Framing: line-oriented commands

### 1. Command Format (Betaflight-inspired)

```
<command> [<parameter1>] [<parameter2>] ... [<parameterN>]\r\n
```

Implementation note:
- WiFi TCP driver buffers bytes until CR/LF and submits one command line to RPC.
- Bluetooth SPP driver submits received chunks to RPC transport; commands should still be sent as line-based text.

**Examples:**
```
get system emergency_stop_enabled
set system emergency_stop_enabled true
save
set controller 0 0 0 0 0 0 0 0 0 0 0 0 0 0 0 0 0 0 0 0 0 0 0 0 0 0 0 0 0 0 0 0
```

### 2. Response Format

```
# Command successful (single line)
<result_data>

# Command failed (single line)
ERROR <details>
```

Implementation note:
- Current RPC implementation returns CRLF-terminated response lines and does not emit an additional trailing `OK` marker.
- `set controller` intentionally emits no response for high-frequency input updates.

### 3. Command Set and Support Matrix

Commands in this matrix are authoritative.

| Command | Support | Notes |
| --- | --- | --- |
| `help` | Implemented | Returns available command list |
| `version` | Implemented | Returns firmware/IDF version string |
| `list namespaces` | Implemented | Uses config manager runtime registry |
| `list <namespace>` | Implemented | Returns parameters for namespace |
| `get <namespace> <parameter>` | Implemented | Typed read via config manager |
| `set <namespace> <parameter> <value>` | Implemented | Memory-only write |
| `setpersist <namespace> <parameter> <value>` | Implemented | Write + persist |
| `save [<namespace>]` | Implemented | Persist one or all namespaces |
| `export <namespace>` | Partially implemented | `system` currently supported |
| `factory-reset` | Implemented | Erases robot config namespaces and reloads defaults |
| `set controller <ch0> ... <ch31>` | Implemented | High-rate ingress, no response line |
| `import <namespace> <data>` | Planned | Not implemented |
| `reload [<namespace>]` | Planned | Not implemented |
| `info <namespace> <parameter>` | Planned | Not implemented |
| `joint`, `jointangle`, `leg`, `pose`, `gait`, `stop`, `home` | Planned | Not implemented |
| `status`, `reboot`, `cpu`, `memory`, `tasks` | Planned | Not implemented |

### 4. Command Categories

#### ✅ Implemented Commands
```bash
# Individual parameter access  
✅ get <namespace> <parameter>           # Get single parameter
✅ set <namespace> <parameter> <value>   # Set single parameter (memory)
✅ setpersist <namespace> <parameter> <value>  # Set and save to NVS

# Bulk operations
✅ export <namespace>                    # Get all parameters in a portable form  

# Management
✅ save [<namespace>]                    # Save namespace(s) to NVS
✅ factory-reset                         # Factory reset (explicit destructive operation)
✅ list namespaces                       # List all available namespaces
✅ list <namespace>                      # List parameters in namespace  

# System information
✅ help                                  # List available commands
✅ version                               # Firmware version and build info

# Control ingress
✅ set controller <ch0> ... <ch31>       # Update controller channels
```

#### 🔲 Planned Commands
```bash
🔲 import <namespace> <data>             # Set all parameters from provided data
🔲 reload [<namespace>]                  # Reload namespace(s) from NVS
🔲 info <namespace> <parameter>          # Get parameter metadata
```

#### 🔲 Robot Control Commands (Planned)
```bash
# Joint control (servo-level)
🔲 joint <leg> <joint> <position>        # Set joint to PWM position (1000-2000)
🔲 jointangle <leg> <joint> <angle>      # Set joint to angle (degrees)

# Leg control (inverse kinematics)  
🔲 leg <leg> move <x> <y> <z>           # Move leg tip to XYZ position (mm)
🔲 leg <leg> home                       # Move leg to home position
🔲 leg <leg> status                     # Get leg position and status

# Robot control
🔲 pose <roll> <pitch> <yaw> <x> <y> <z> # Set robot body pose
🔲 gait <type> <speed>                  # Start gait pattern  
🔲 stop                                 # Emergency stop
🔲 home                                 # Move all legs to home position
```

#### 🔲 System Commands (Planned)
```bash
🔲 status                               # System status (voltages, temps, errors)
🔲 reboot                              # Reboot system
🔲 cpu                                 # CPU usage and performance stats
🔲 memory                              # Memory usage statistics  
🔲 tasks                               # FreeRTOS task information
```

## Configuration Integration

### 1. Hybrid Configuration API Usage

The RPC system will leverage our hybrid configuration system:

```c
// Individual parameter access (Approach B)
esp_err_t rpc_cmd_get(const char* namespace, const char* param) {
    // Use hexapod_config_get_* functions based on parameter type
    config_param_info_t info;
    hexapod_config_get_parameter_info(namespace, param, &info);
    
    switch(info.type) {
        case CONFIG_TYPE_BOOL:
            bool value;
            hexapod_config_get_bool(namespace, param, &value);
            rpc_send_response("get: %s", value ? "true" : "false");
            break;
        // ... other types
    }
}

// Bulk operations (Approach A) 
esp_err_t rpc_cmd_export_system() {
    const system_config_t* config = config_get_system();
    rpc_send_json_response(config);  // Serialize to JSON
    return ESP_OK;
}
```

### 2. Bulk Data Transfer Optimization

For efficient configurator operation:

```bash
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

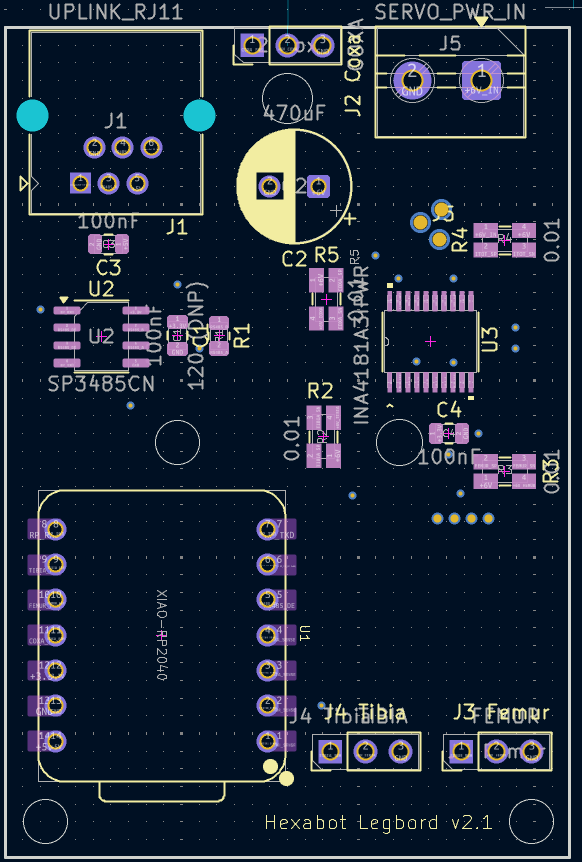
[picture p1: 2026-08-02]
hardware/legboard/board-front.png

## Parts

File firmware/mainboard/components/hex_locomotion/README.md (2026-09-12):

# hex_locomotion

## Role
Locomotion command and trajectory pipeline.

## Contents
- user_command.c
- gait_scheduler.c/.h
- swing_trajectory.c/.h
- whole_body_control.c/.h
- motion_math.h (shared clampf/fracf/quintic_smoothstep helpers)

## Responsibilities
- Poll and map controller input into user commands.
- Compute gait phase and leg support/swing states, using a Wilson gait
  continuum: swing fraction (duty factor) and per-leg phase offsets scale
  continuously with commanded speed instead of switching between 3
  hardcoded gaits (see `gait_scheduler.c` and the `gait` namespace's
  `duty_factor_min`/`duty_factor_max`).
- Generate swing trajectories, with a quintic (minimum-jerk) horizontal
  sweep during swing for zero-velocity touchdown.
- Convert trajectories into per-leg joint commands.

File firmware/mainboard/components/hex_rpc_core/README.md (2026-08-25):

# hex_rpc_core

## Role
RPC command parsing, command dispatch, and RPC processing task orchestration.

## Responsibilities
- Parse inbound ASCII RPC commands and tokenize arguments.
- Dispatch to config, controller, actuation/IK diagnostic, and system command handlers.
- Run the RPC processing task that consumes transport RX messages.
- Emit responses through registered transport send callback or transport TX queue.

## Public Surface
- Header: rpc_commands.h
- Core APIs:
  - rpc_init
  - rpc_feed_bytes
  - rpc_poll
  - rpc_set_send_callback
- Commands: `get`/`set`/`setpersist`/`export`/`save`/`list`/`factory-reset` (config),
  `set controller` (high-rate channel stream), `help`/`version`, and two RS485
  bring-up/diagnostic commands that bypass gait/IK via `hex_actuation`'s manual
  per-leg override:
  - `joint <leg 1-6> <coxa_deg> <femur_deg> <tibia_deg>` / `joint <leg> release`
  - `ik <leg 1-6> <x_m> <y_m> <z_m>` (leg-local Cartesian target -> IK -> same override)

## Integration
- Consumes inbound bytes/messages from hex_rpc_transport.
- Uses hex_config_manager for configuration get/set/list/save operations, including
  the `joint_cal` namespace's per-joint `min_rad`/`max_rad` as the range clamp for
  the `joint`/`ik` commands above (not a locally-invented constant).
- Uses controller internal channel update path for high-rate controller set commands.
- Uses hex_actuation's manual joint override and hex_robot_config's per-leg IK handle
  for the `joint`/`ik` diagnostic commands.

## SDKConfig Requirements (Current Project)
- No dedicated module-specific Kconfig toggles are required.
- Depends on project FreeRTOS support and task creation configuration.

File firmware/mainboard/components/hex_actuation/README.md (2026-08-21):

# hex_actuation

## Role
Final stage of the motion pipeline: converts whole-body/IK joint commands into
RS485 leg commands. The ESP32 does **not** generate servo PWM itself in V2 —
that happens locally on each LegBoard (RP2040) — so this component's job is
forwarding, not driving hardware directly. See
`docs/architecture/SYSTEM_ARCHITECTURE.md` and
`docs/architecture/HARDWARE_AND_MECHANICS.md`.

## Contents
- robot_control.c
- robot_control.h

## Responsibilities
- `robot_execute()`: called every 10ms from the gait loop (`main.c`) with the
  whole-body command; converts each leg's IK joint angles (radians) to degrees
  and forwards them to `hex_rs485_master` via `rs485_master_set_leg_angles()`.
  Performs the unit conversion only — no clamping, offsets, or PWM mapping,
  which all live on the LegBoard (see `firmware/leg/src/servo.cpp`).
- Manual per-leg joint override for RS485 bring-up/diagnostics: while active
  for a leg, `robot_execute()` sends the overridden angles for that leg
  instead of the whole-body IK output, so a single joint (or an IK-computed
  Cartesian target) can be exercised directly without the gait loop
  overwriting it 10ms later. Driven by `hex_rpc_core`'s `joint`/`ik` RPC
  commands; cleared per-leg automatically when released.

## Public Surface
- Header: robot_control.h
- Core APIs:
  - `robot_execute(const whole_body_cmd_t *cmds)`
  - `robot_set_leg_joint_override_deg(int leg_index, float coxa_deg, float femur_deg, float tibia_deg)`
  - `robot_clear_leg_joint_override(int leg_index)`
  - `robot_set_joint_angle_rad(...)` — retained for API compatibility with a
    pre-V2 per-joint path; logs only, not the supported way to command a
    joint (use `robot_execute()`, or the manual override above for
    diagnostics).

## Integration
- Consumes `whole_body_cmd_t` from `hex_locomotion`'s whole-body control output.
- Writes to `hex_rs485_master`'s per-leg command buffer.
- Uses `hex_robot_config`/`hex_kinematics` types (`NUM_LEGS`, `leg_servo_t`).
- The manual override is read from and written by two different tasks (the
  100Hz gait loop task and the RPC processing task), so it's guarded by a
  `portMUX_TYPE` spinlock rather than a heap-allocated mutex, avoiding any
  first-use initialization race between them.

## SDKConfig Requirements (Current Project)
- No dedicated module-specific Kconfig toggles are required.
- Depends on project FreeRTOS support (the override spinlock) and the RS485
  UART configuration owned by `hex_rs485_master`.

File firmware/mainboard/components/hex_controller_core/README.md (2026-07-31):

# hex_controller_core

## Role
Controller core runtime plus shared controller-facing interfaces consumed by controller drivers and app logic.

## Public Headers
- controller.h
- controller_internal.h
- user_command.h
- controller.c

## Design Intent
- Keep controller-facing contracts and runtime state out of main.
- Allow drivers and RPC to depend on one stable controller component.
- Preserve non-circular dependency direction by keeping driver startup dispatch in main.

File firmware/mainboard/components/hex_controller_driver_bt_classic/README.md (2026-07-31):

# hex_controller_driver_bt_classic

## Role
Bluetooth Classic SPP controller and RPC transport driver.

## Responsibilities
- Initialize Bluetooth Classic stack and SPP server.
- Handle pairing/authentication callbacks and connection lifecycle.
- Forward incoming SPP payloads into RPC transport RX queue.
- Register transport sender for outbound RPC responses over SPP.
- Trigger failsafe on disconnect or timeout conditions.

## Public Surface
- Header: controller_bt_classic.h
- Core APIs:
  - controller_driver_init_bt_classic
  - controller_bt_classic_send_raw
  - controller_bt_get_device_name

## Integration
- Registered by controller core through driver selection.
- Uses hex_rpc_transport for RPC message exchange.
- Uses controller_internal helpers for shared connection and failsafe behavior.

## SDKConfig Requirements (Current Project)
- Bluetooth stack enabled:
  - CONFIG_BT_ENABLED=y
  - CONFIG_BT_BLUEDROID_ENABLED=y
  - CONFIG_BLUEDROID_ENABLED=y
- Classic Bluetooth mode enabled:
  - CONFIG_BT_CLASSIC_ENABLED=y
  - CONFIG_CLASSIC_BT_ENABLED=y
  - CONFIG_BTDM_CTRL_MODE_BR_EDR_ONLY=y
  - CONFIG_BTDM_CONTROLLER_MODE_BR_EDR_ONLY=y
- SPP profile enabled:
  - CONFIG_BT_SPP_ENABLED=y
- Controller and Bluedroid task affinity and stacks currently configured as:
  - CONFIG_BT_BTC_TASK_STACK_SIZE=3072
  - CONFIG_BT_BTU_TASK_STACK_SIZE=4352
  - CONFIG_BTDM_CTRL_PINNED_TO_CORE=0
  - CONFIG_BLUEDROID_PINNED_TO_CORE=0

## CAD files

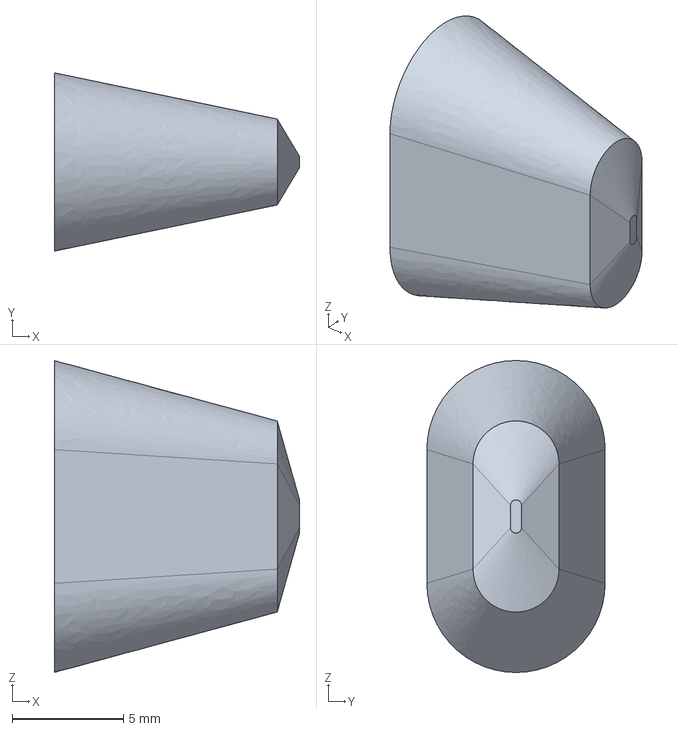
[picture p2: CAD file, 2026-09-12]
hardware/models/hexapod_v2.FCStd
11.0 x 8.00 x 14.0 mm

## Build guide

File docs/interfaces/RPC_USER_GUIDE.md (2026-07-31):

# Hexapod RPC User Guide

## Overview

The Hexapod firmware exposes a text-based RPC interface for runtime configuration and control ingress.

This guide is operational-only:
- how to connect
- how to send commands safely
- practical workflows for tuning and persistence

For authoritative protocol behavior (supported commands, framing, and semantics), see [RPC_SYSTEM_DESIGN.md](RPC_SYSTEM_DESIGN.md).

## Transport Setup

### Bluetooth Classic SPP

1. Power on the robot.
2. Pair with device name `HEXAPOD_XXXXXX` (MAC suffix).
3. Use PIN `1234` unless changed.
4. Open the outgoing virtual COM port in your terminal.

Notes:
- One SPP client is supported at a time.
- Transport is a byte stream; send text commands terminated with newline.

### WiFi TCP

1. Connect to the robot AP.
2. Open a TCP connection to the configured listen port.
3. Send line-based text commands terminated with `\n` or `\r\n`.

Notes:
- One active TCP client session is supported at a time.

## Command Format

General form (refer to canonical contract for full command semantics):

```text
<command> [arg1] [arg2] ...
```

Examples:

```text
list namespaces
list system
get system emergency_stop_enabled
set system emergency_stop_enabled true
setpersist wifi tcp_listen_port 5555
save wifi
export system
```

High-rate controller ingress:

```text
set controller <ch0> <ch1> ... <ch31>
```

If fewer than 32 channel values are provided, missing channels are set to `0`.

Tip:
- Run `help` and `list namespaces` on the connected target to discover runtime-supported operations.

## Response Behavior

- Responses are CRLF-terminated text lines.
- Current implementation does not append a separate trailing `OK` line.
- Most commands return one line with either data or an `ERROR ...` message.
- `set controller ...` intentionally returns no response to avoid extra traffic.

Typical responses:

```text
namespaces: system, joint_cal, leg_geom, motion_lim, controller, wifi
emergency_stop_enabled=true
emergency_stop_enabled=true (persist)
save system: OK
ERROR set emergency_stop_enabled
```

## Limits and Validation

- Maximum input line length is 255 characters in the RPC parser.
- Overlong lines return `ERROR line too long`.
- Parameters are type-checked and range-validated by config manager descriptors.

## Practical Workflows

### Read and tune one parameter

```text
get motion_lim max_velocity_coxa
set motion_lim max_velocity_coxa 4.5
setpersist motion_lim max_velocity_coxa 4.5
```

### Tune gait trajectory parameters

```text
list gait
get gait cycle_time_s
get gait step_length_m
set gait step_length_m 0.09
setpersist gait max_yaw_per_cycle_rad 0.35
setpersist gait turn_direction 1.0
save gait
```

Notes:
- `cycle_time_s`, `step_length_m`, and `clearance_height_m` control high-level gait timing and swing shape.
- `y_range_m`, `z_min_m`, and `z_max_m` control pose-to-foot target mapping.
- `max_yaw_per_cycle_rad` and `turn_direction` control turning behavior.

### Tune controller stick deadband

```text
get controller stick_deadband
set controller stick_deadband 0.03
setpersist controller stick_deadband 0.03
save controller
```

Notes:
- `stick_deadband` is clamped and validated in range `0.0 .. 0.3`.
- Lower values increase stick sensitivity near center; higher values suppress noise.

### Tune controller failsafe command profile

```text
list controller
get controller failsafe_enable
set controller failsafe_enable 1
set controller failsafe_gait 2
set controller failsafe_step_scale 0.4
setpersist controller failsafe_vx 0.0
setpersist controller failsafe_wz 0.0
setpersist controller failsafe_z_target -0.1
setpersist controller failsafe_pose_mode 1
save controller
```

Notes:
- Failsafe profile is applied when controller input is unavailable.
- `failsafe_gait` values are `0=wave`, `1=ripple`, `2=tripod`.
- Float constraints: `failsafe_vx`, `failsafe_wz`, `failsafe_z_target`, `failsafe_y_offset` in `-1.0 .. 1.0`, `failsafe_step_scale` in `0.0 .. 1.0`.

### Save all dirty namespaces

```text
save
```

### Factory reset

```text
factory-reset
```

This erases robot configuration namespaces and reloads defaults. Use with care.

## Troubleshooting

- No response:
  - verify transport connection (Bluetooth COM/TCP socket)
  - verify newline-terminated commands
- `unknown: <cmd>`:
  - command not implemented
- `set: not found` or `get: not found`:
  - wrong namespace or parameter name
- frequent disconnects:
  - check WiFi/Bluetooth link quality and timeout settings

## Related Documentation

- See [RPC_SYSTEM_DESIGN.md](RPC_SYSTEM_DESIGN.md) for the canonical RPC command contract.
- See [WIFI_TCP_PROTOCOL.md](WIFI_TCP_PROTOCOL.md) and [BLUETOOTH_CLASSIC_PROTOCOL.md](BLUETOOTH_CLASSIC_PROTOCOL.md) for transport-specific context.

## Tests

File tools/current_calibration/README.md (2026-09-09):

# LegBoard current-sensor calibration

Calibrates a LegBoard's INA4181 current sensing (see
`firmware/leg/src/current.cpp`) against a known load, instead of a
multimeter and manual math each time. Meant to be run once per LegBoard (and
again after any hardware rev).

## Hardware setup

1. Plug the calibration adapter board (`hardware/calboard/`,
   `firmware/calboard/`) into the LegBoard's J2/J3/J4 servo connectors in
   place of real servos.
2. Power the LegBoard normally (RS485 not required — this script talks to it
   directly over its USB calibration serial port).
3. Plug both the LegBoard and the calboard into this PC over USB.

## Usage

```bash
pip install -r requirements.txt
python calibrate_current.py                    # auto-detects both boards' ports
python calibrate_current.py --leg COM5 --cal COM7   # or specify explicitly
python calibrate_current.py --no-push           # fit + report only, don't write to the leg's flash
```

The script:
1. Steps each joint's channel (coxa/femur/tibia) through the calboard's
   15-step resistor ladder via the LegBoard's `PWM <joint> <us>` command,
   pairing the LegBoard's raw ADC reading (`CURRAW?`) against the calboard's
   computed ground-truth current (`READ?`) at each step.
2. Repeats with all three joints driven together for the `total` channel,
   using the sum of the three calboard channels as ground truth.
3. Least-squares fits `mA = scale * raw_mV + offset` per channel and reports
   R² (warns below 0.98 — check wiring/settle time before trusting a low-R²
   fit).
4. Pushes each channel's `scale`/`offset` to the LegBoard via `CURCAL`
   (persisted to flash — see `firmware/leg/src/persist.cpp`), unless
   `--no-push` is given.
5. Writes a timestamped CSV of every raw sample for traceability.

See `firmware/leg/src/calib.cpp` and `firmware/calboard/src/usbserial.cpp`
for the exact command protocols this script drives.

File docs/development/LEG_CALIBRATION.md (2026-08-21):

# LegBoard Configurator (Address + Current-Sense + Servo PWM/Sign Calibration)

## What this is

An interactive wizard for bringing up one LegBoard: assign its RS485
address, then guide a resistor-based calibration of its per-servo current
sense (INA4181 + shunt, one channel per servo), plus a separate flow to
recalibrate each servo's true physical center. Everything is driven
directly over the LegBoard's own USB serial console
(`firmware/leg/src/calib.cpp`) via
[`tools/leg_configurator.py`](../../tools/leg_configurator.py) — no separate
calibration board or RS485 link is needed, since the LegBoard already
exposes everything required (`ADDR` for identity, `CURRAW?`/`CURCAL` for
current calibration, `PWM`/`PWMNEUTRAL`/`INVERT` for servo PWM) locally.

(An earlier iteration of this tool used a second RS485-master board
("s-calib") on a spare LegBoard PCB, for a scenario where the target board
had no USB access of its own. That's not the common case — a LegBoard being
brought up is normally plugged straight into a PC — so it was dropped in
favor of talking to the target's own USB console directly.)

## Connect

Plug the target LegBoard into your PC via USB, then:

```bash
python tools/leg_configurator.py
```

The port is auto-detected (it looks for the RP2040's USB VID, so unrelated
ports like Bluetooth virtual COM ports are filtered out first) — pass
`--port COM10` explicitly if you ever need to override it, e.g. more than
one RP2040 board is plugged in at once.

(If you don't have `pyserial` in your default Python, run this with
PlatformIO's bundled interpreter instead — see the script's `--help`.)

## Modes (`--mode`)

The script covers three distinct jobs on one LegBoard; `--mode` picks which
to run:

| `--mode` | Runs |
|---|---|
| `full` (default) | leg address → current-sense calibration → servo calibration, in sequence |
| `address` | just the leg address step, nothing else |
| `current` | current-sense calibration only (sections 3-5 below) |
| `servo` | servo calibration only: PWM center, direction check, range walk (below) |

`address` skips the board diagram (no wiring involved); `current` and
`servo` both show it first and confirm/set the address, since either one
needs you to know which physical connector is which. `--channels
coxa,femur,tibia` (default: all three) narrows which joints/channels
`current` and `servo` touch — same names, two different index namespaces
under the hood (current-sense channel vs. PWM joint).

## 1. Leg address

The wizard reads the board's current address first (`ADDR?`):

- If it's already set (1-6), that value is offered as the default — press
  Enter to keep it, or type a new one to change it.
- If the board is uncalibrated (address `0` — see `firmware/leg/README.md`
  "Uncalibrated-board marker"), you're required to enter one (1-6) before
  continuing.

Either way it's confirmed and persisted via `ADDR <n>` before moving on.

## 2. Board diagram

The wizard then prints an ASCII top-view of the LegBoard so you know which
physical connector is which before touching anything — J2/J3/J4 map to
coxa/femur/tibia respectively (confirmed against
`hardware/legboard/legboard_sch.py`, not just the silkscreen). It's a
hand-drawn approximation of the rendered board
(`hardware/legboard/board-front.png`), not pixel-derived from the image —
see `docs/plans/TODO.md` for auto-generating it from the real board render
as a possible follow-up.

## Current-sense calibration (`--mode current`, and part of `full`)

Guides a resistor-based calibration of the per-servo current sense (INA4181
+ shunt, one channel per servo plus `total`).

### 3. Zero-load offsets (all 4 channels at once)

The wizard asks you to disconnect all three servos, then Enter takes one
averaged `CURRAW?` reading (5 samples) that covers **total/coxa/femur/tibia
in a single step** — one poll already reports all 4 channels, so there's no
separate "now disconnect for total" pass. Whatever raw mV each channel
reports at zero load *is* that channel's offset error (true current is 0
there by definition).

This first prompt also takes **Esc instead of Enter** to skip current-sense
calibration entirely for this run, leaving whatever is already stored on the
board untouched — handy if you only came to check/adjust servo centers
(`--mode servo`) and don't need to redo current calibration.

Offset matters far more than scale for this hardware: the INA4181 gain +
shunt put scale theoretically at 1.0, and it lands around 0.97-0.99 in
practice — a small correction — while the offset can meaningfully skew
low-current readings if left uncorrected. So this single step alone is
already a reasonable calibration.

### 4. Choose how far to take it

After the offsets are measured, the wizard asks:

```
More precise calibration with resistors? [y/N], or enter a scale (0-2)
to use for every channel together with the offsets above:
```

- **Enter / `n` (default)** — write `scale=1.0` with the just-measured
  offset to all 4 channels and stop. Fastest path, good enough for most
  boards.
- **A number 0-2** — use that as the scale for all 4 channels (still paired
  with each channel's own measured offset). Handy if you already know this
  batch of boards runs close to e.g. 0.98 and want to skip the resistor
  dance entirely.
- **`y`** — go on to full per-channel resistor calibration (below), reusing
  the zero point already measured instead of re-measuring it per channel.

### 5. Resistor calibration (optional, `y` above)

For each of coxa/femur/tibia in turn, the wizard attaches a spread of known
resistor loads and fits a line through the (already-measured) zero point
plus all of them by least squares, calling out the exact connector (e.g.
"J2 (coxa)") at each step:

1. Attach each of four suggested THT resistor values in turn — **470 Ω,
   220 Ω, 100 Ω, 47 Ω** (common E12 values, low-to-high current). No
   confirmation keypress needed for the attach step itself: the wizard
   live-updates the raw reading on one line and auto-detects once it has
   moved away from the zero-point baseline and settled (on Windows, you can
   also just press Enter to force a manual reading, e.g. if the change is
   too small to trip the threshold). Once settled, it takes the recorded
   value as an average of 5 fresh individual readings — not just whichever
   single noisy poll happened to trip the detector. It then asks for the
   reference current (mA), defaulting to whatever you entered for that
   resistor value last time — press Enter to accept — or a theoretical `V/R`
   guess on the very first run. The wizard prints the minimum power rating
   needed per value (table below) — these are deliberately small, low-power
   loads; you do **not** need to source amps through a resistor.
2. The wizard fits `current_ma = scale × raw_mv + offset` by ordinary least
   squares over the zero point + all 4 span points and persists it with
   `CURCAL <ch> <scale> <offset>` — the same command `calib.cpp` already
   exposes for manual/bench calibration.
3. **`total` is calibrated too, for free.** `CURRAW?` reports all 4
   channels on every poll, so every coxa/femur/tibia span measurement above
   doubles as a `total` (channel 0) data point at no extra cost — no
   separate steps, no extra resistor attachments. The zero point from step 3
   is included too. After all selected branches are done, the wizard fits
   and persists `total` from whatever points got collected along the way.
   **This is only valid if the other two branches stay disconnected for the
   entire session**, not just their own step — the wizard prints a reminder
   before starting. If you only ran a subset of channels (`--channels`),
   `total`'s fit is based on just those branches' points.

**Redo a step, or just re-measure.** Made a mistake — wrong resistor,
mis-typed current, bumped a lead? At any reference-current prompt (or as a
bare keypress while a reading is live, on Windows):
- `b` discards the current step and redoes the *previous* one (as far back
  as the first resistor step — the zero point was already measured in step 3
  and isn't redone here).
- `r` re-measures the *current* step in place (same resistor, fresh
  reading) without losing your spot in the sequence.

| Load | ≈ current @ 6V rail | Min. resistor power |
|---|---|---|
| open | 0 mA (zero point) | — |
| 470 Ω | ~13 mA | 1/4 W |
| 220 Ω | ~27 mA | 1/4 W (1/2 W recommended) |
| 100 Ω | ~60 mA | 1/2 W |
| 47 Ω | ~128 mA | 1 W |

The "≈ current" column is only for picking a safe resistor — the wizard
always asks you to type in the *actual* measured/computed reference current
for each point, so real rail voltage and resistor tolerance don't matter for
accuracy.

**Extrapolation, not a full-range test.** These calibration points stay in
the tens-of-mA range on purpose — the INA4181 current-shunt amplifier is
linear by design, so a handful of low-power points is enough to fix the
line; there's no need (and no safe simple way) to physically source amps
through a small THT resistor. Pushing several amps through a resistor tied
to the servo's 6V rail dissipates tens of watts.

```bash
python tools/leg_configurator.py --mode current --port COM10                     # all three channels
python tools/leg_configurator.py --mode current --port COM10 --channels coxa     # just one
```

## Servo calibration (`--mode servo`, and part of `full`)

Recalibrates each servo's true physical center, checks that it moves the
right direction, and optionally walks its full safe range — all on an
assembled leg, driven purely over USB with the leg's own console (no RS485,
no mainboard needed). For each selected joint, in turn:

### 6. Center

A leg's true physical zero-degree pose isn't always reachable at exactly
1500 µs — a servo horn can't always be mounted perfectly centered on a given
leg's mechanical build, especially the femur/tibia links where a single
spline tooth of offset can be the difference between "close enough" and
visibly off. The wizard puts the joint into a live jog: the pulse width and
key legend redraw on one line as you go, and the leg moves in real time --

- **↑ / ↓** — fine adjust, ±5 µs (`JOG_STEP_FINE_US`)
- **← / →** — coarse adjust, ±25 µs (`JOG_STEP_COARSE_US`)
- **Enter** — accept the current value and persist it as the new center via
  `PWMNEUTRAL <joint> <us>`
- **Esc** — cancel, restoring whatever pulse width the joint had before you
  started jogging it (nothing persisted)

(Piped/non-interactive stdin, where arrow keys aren't available, falls back
to typing an exact pulse width plus Enter.)

Unlike a raw `PWM` override, accepting a new center **is** persisted (flash,
survives reboot) and takes effect immediately for normal operation too:
`servo_write_angle()` (used for every RS485-driven and interpolated move) is
anchored at the calibrated neutral, with independent linear spans out to the
(still compile-time) min/max pulse on either side — so recalibrating the
center shifts where a commanded angle of 0° physically lands without
distorting the endpoints.

### 7. Gentle direction check

Immediately after centering that joint, the wizard nudges it a small amount
(`--step` µs, default 100) to each side of the just-set center, one move at
a time — Enter to continue, `q` to quit — so you can watch which physical
direction each move produces before anything bigger happens. Current is
sampled at every step against a just-measured neutral baseline and flagged
if it jumps well above it (informational only — a heads-up to look closer,
not a hard cutoff, since the board may not be current-calibrated yet).

After both nudges it asks what direction you saw, and prints the direction a
*positive* commanded angle is supposed to produce per the mainboard IK's
leg-local convention — see
[`HARDWARE_AND_MECHANICS.md` "Joint Angle Sign Convention"](../architecture/HARDWARE_AND_MECHANICS.md#joint-angle-sign-convention)
— for femur and tibia (coxa's expected yaw direction depends on this leg's
mount rotation, which the wizard has no access to, so there's no universal
answer to print there). If what you saw doesn't match, it offers to flip and
persist that joint's sign (`INVERT <joint> <1|-1>`) right there and re-runs
the nudge so you can confirm the fix immediately, rather than discovering an
inverted joint later during an IK/gait test.

### 8. Extended range walk (optional)

After all selected joints' gentle checks, the wizard asks once whether to
also walk each joint toward its min/max pulse width in the same small
increments — still step-confirmed and current-monitored — to find the safe
usable range without jamming anything (leg geometry can make the real usable
range narrower than the servo's own 500-2500 µs).

All joints return to their (possibly just-recalibrated) center at the end,
or immediately if you quit early with `q`.

```bash
python tools/leg_configurator.py --mode servo --port COM10                  # all three joints
python tools/leg_configurator.py --mode servo --port COM10 --channels femur # just one
python tools/leg_configurator.py --mode servo --port COM10 --step 150       # bigger nudge
```

Query the current persisted centers and signs directly over the console at
any time:

```
PWMNEUTRAL?
J0 coxa neutral_us=1500
J1 femur neutral_us=1460
J2 tibia neutral_us=1500

INVERT?
J0 coxa invert=1
J1 femur invert=-1
J2 tibia invert=-1
```

Angle range (`angle_min_deg`/`angle_max_deg`) is not yet calibratable this
way — still a compile-time default (±90°), see `firmware/leg/README.md`
"Bring-Up Status/TODO".

## Zero-position build aid

`--zero` (independent of `--mode`) centers all three servos to each joint's
*calibrated* PWM neutral (`PWMNEUTRAL?`, previous section — 1500 µs /
`DEFAULT_PWM_NEUTRAL_US` until recalibrated) via the raw `PWM <joint> <us>`
override, without running any calibration, so the leg can be physically
assembled against a fixed mechanical reference:

```bash
python tools/leg_configurator.py --port COM10 --zero
```

This is a raw override, not persisted — it releases as soon as the board
gets a real target (e.g. once it's wired to the mainboard) or power-cycles.
(The PWM neutral it centers to, unlike this override itself, *is*
persisted.)

## Hardware current range

The LegBoard's INA4181A3 (100 V/V, fixed) + 10 mΩ Kelvin shunts
(`hardware/legboard/legboard_sch.py`, all four channels identical today) cap
out at:

```
I_max = Vref / (Gain × Rshunt) = 3.3 V / (100 × 0.01 Ω) ≈ 3.3 A per channel
```

That's a hard ADC-saturation ceiling — no calibration, software or
otherwise, can measure above it on the current hardware. It's adequate for
a single servo branch (coxa/femur/tibia), but the `total` channel sums up to
three branches and can see meaningfully more under worst-case simultaneous
stall. The wizard's `total` fit (previous section) is still just an
extrapolation from tens-of-mA points, same as the branches — it doesn't
change this ceiling. A shunt change for the total channel only (R4:
10 mΩ → ~3 mΩ, raising its ceiling to ~11 A) is planned but not yet done —
see `docs/plans/TODO.md`. Until then, treat ~3.3 A as the real ceiling on
every channel, including `total`.

## Related docs

- [`../interfaces/RS485_PROTOCOL.md`](../interfaces/RS485_PROTOCOL.md) — wire protocol (current-sense calibration is deliberately not part of it — see "Stored Parameters")
- [`../../firmware/leg/README.md`](../../firmware/leg/README.md) — the LegBoard's own firmware and USB console
- [`../../tools/serial_console.py`](../../tools/serial_console.py) — generic line-buffered serial console (manual `calib.cpp` commands, local echo, sends on Enter) if you'd rather drive it by hand

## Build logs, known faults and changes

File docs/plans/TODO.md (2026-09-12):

# Hexapod Robot Project TODO List

## 🎯 Project Vision & New Goals

### Mechanical Improvements (observed on the built robot, 2026-09)

Robot walks and all electronics work, but two mechanical issues are visibly
limiting gait quality right now — higher near-term leverage than more
software gait work until addressed. Also filed as
[GH issue #4](https://github.com/quick-brown-bot/hexapod_v2/issues/4).

- [ ] **TPU foot tips ("shoes") to fix slipping** — in progress
  - Feet slip badly on the current surface/tips; robot loses traction during
    swing→stance transitions and while turning
  - Foot tip added to the leg model in `hardware/models/hexapod_v2.FCStd`;
    still needs printing in TPU, mounting, and on-robot slip validation
    (also re-evaluate whether the quintic swing trajectory shaping is still
    needed once tips are on)
- [x] **Coxa servo hinge play causing Z-axis sag** — fixed for now (2026-09)
  - Stiffened the coxa horn/hinge mechanical interface; needs to be
    monitored for recurrence with continued use (wear, more running hours)
    before calling it fully resolved. Femur/tibia joints not yet audited for
    the same issue.

### Hardware Improvements
- [ ] **Touch sensors at each leg**
  - Research suitable force/pressure sensors for leg-ground contact detection
  - Design mounting system for sensors on leg tips
  - Implement sensor reading and processing
  - Integrate touch feedback into gait control system

- [ ] **Electronics & Power System Upgrade**
  - Replace/improve current power board to ESP32 connectors
  - Design more reliable electrical connections
  - Consider PCB design for better signal integrity
  - Implement proper power management and distribution

- [ ] **LegBoard total-current shunt resize (R4) for ~9A range on the total channel**
  - Today all four current-sense channels share identical hardware:
    INA4181A3 (100 V/V, fixed for the whole quad IC) + 10 mΩ Kelvin shunts
    (`hardware/legboard/legboard_sch.py` R2-R5), giving `I_max = Vref /
    (Gain×Rshunt) = 3.3V / (100×0.01Ω) ≈ 3.3A` per channel — fine for a
    single servo branch, but the `total` channel sums up to 3 branches and
    should have headroom toward ~9A under worst-case simultaneous stall
  - Plan: resize **R4 only** (total shunt) from 10 mΩ to ~3 mΩ →
    `I_max ≈ 11A`, keep R2/R3/R5 (coxa/femur/tibia branches) at 10 mΩ (gain
    is shared across the IC, so only the shunt value can differ per channel)
  - Requires: schematic/BOM edit via the hardware-schematics skill; physical
    rework (desolder/resolder R4) on any already-populated LegBoards; and a
    firmware change so `persist.cpp`'s default current-sense scale is
    per-channel (`total` ≈ 3.333 mA/mV, branches 1.0 mA/mV) instead of one
    shared `DEFAULT_ISENSE_MA_PER_MV` constant in `config.h`
  - Deferred until the next board order/rework pass. See
    `docs/development/LEG_CALIBRATION.md` "Hardware current range" for the
    derivation and current (~3.3A, all channels) status quo

- [ ] **Auto-generate the LegBoard ASCII diagram in `tools/leg_configurator.py`**
  - `BOARD_DIAGRAM` in `tools/leg_configurator.py` is hand-drawn (from
    `hardware/legboard/legboard_sch.py` placement +
    `hardware/legboard/board-front.png`), not derived from the real board
    render — fine for now (connectors don't move often) but will drift if the
    layout changes and nobody remembers to update it by hand
  - Idea: script `hardware/legboard/board-front.png` (or better, live
    placement data from `legboard_sch.py`) into a small ASCII/box-drawing
    renderer keyed by reference designator, so the diagram regenerates
    alongside the schematic instead of being maintained separately
  - Low priority / nice-to-have — plain text is manually accurate enough for
    now

- [ ] **IMU Integration for Terrain Leveling**
  - Add IMU sensor (accelerometer + gyroscope)
  - Implement body position/orientation estimation
  - Develop terrain leveling algorithms
  - Integrate IMU feedback into whole body control system

### Controller Systems
- [ ] **FlySky Controller Reconnection**
  - Debug signal stability issues caused by electronics interference
  - Implement proper signal filtering/shielding
  - Test and validate reliable communication
  - Add failsafe mechanisms

- [ ] **ESP-NOW Controller Implementation**
  - Design ESP-NOW communication protocol
  - Implement controller device (separate ESP32)
  - Add wireless communication handling
  - Create user interface for ESP-NOW controller

### Vision & Processing
- [ ] **Jetson Nano Integration**
  - Add Jetson Nano compute module to the system
  - Design mounting and power solution
  - Implement dual camera system
  - Develop computer vision capabilities
  - Create communication bridge between ESP32 and Jetson Nano

### Configuration & Tuning Portal
- [ ] **Hexapod Configurator (Betaflight-inspired)**
  - Design web-based configuration portal for robot tuning
  - Implement RPC-like communication protocol between configurator and ESP32
  - Create real-time parameter adjustment interface
  - Add live telemetry and monitoring capabilities
  - Implement configuration backup/restore functionality

### Bio-Inspired & Research-Backed Locomotion

These items upgrade the open-loop phase-table gait engine
(`gait_scheduler.c` → `swing_trajectory.c` → `whole_body_control.c` → `kpp_system.c`)
toward biologically-grounded, continuously-adaptive locomotion. Each item is
anchored to published research. Tiers reflect hardware dependency, not priority.

#### Tier 1 — Pure software (no new hardware; works on v1)
- [ ] **Wilson gait continuum (continuously-variable duty factor)**
  - Replace the 3 discrete gaits (tripod/ripple/wave) and their hardcoded duty
    factors (`S` in `swing_trajectory.c:60-65`) with a single continuum where
    duty factor `β` decreases with commanded speed (slow→wave, fast→tripod)
  - Derive per-leg phase offsets from one wave parameter in `gait_scheduler.c`
  - Replaces the "crude frequency scaling" TODO (`gait_scheduler.c:22-26`)
  - Highest effort/payoff ratio; foundation for the CPG item below
  - Ref: Wilson, D.M. (1966), "Insect Walking", *Annual Review of Entomology* 11:103-122
  - Ref: Graham, D. (1985), "Pattern and Control of Walking in Insects", *Advances in Insect Physiology* 18:31-140

- [ ] **CPG gait engine — coupled phase oscillators**
  - Replace the phase *table* in `gait_scheduler.c` with 6 coupled oscillators
    (Kuramoto / Hopf) whose phase-locking encodes the gait; preserve the existing
    `phase` / `leg_states` output contract so downstream stages are unchanged
  - Enables smooth online gait transitions (no popping at speed thresholds) and
    automatic re-synchronization after disturbance
  - Keep phase tables behind a config flag as fallback
  - Natural injection point for sensory feedback (see Tegotae, Tier 3)
  - Ref: Ijspeert, A.J. (2008), "Central pattern generators for locomotion control in animals and robots: a review", *Neural Networks* 21(4):642-653
  - Ref: Righetti & Ijspeert (2008), "Pattern generators with sensory feedback for the control of quadruped locomotion", *IEEE ICRA*

- [x] **Minimum-impact swing foot trajectory (zero-velocity touchdown)** — done
  on `quintic-swing-trajectory` branch
  - Horizontal sweep during swing now uses a quintic (minimum-jerk)
    smoothstep instead of linear `disp = (-0.5+tau)*L`
    (`swing_trajectory.c`), giving zero foot velocity/acceleration at
    lift-off and touchdown instead of an instantaneous reversal → should
    reduce foot slip and servo shock. Same shaping applied to the yaw-turn
    sweep. Vertical arc (sine) and support-phase motion unchanged.
  - Needs on-robot validation: does slip/shock visibly improve? (partially
    superseded as a fix for slip by the TPU feet item below — see
    "Mechanical improvements" section)
  - Ref: Raibert, M. (1986), *Legged Robots That Balance*, MIT Press
  - Ref: Park, Wensing & Kim (2017), "High-speed bounding with the MIT Cheetah 2", *IJRR* 36(2):167-192 (swing-leg trajectory design)

- [ ] **Holonomic (omnidirectional) body velocity — lateral `vy` + crab walk**
  - `user_command_t` currently carries only `vx` (forward) and `wz` (yaw); the
    robot cannot strafe. Add a lateral `vy` term and compose the full planar
    twist (vx, vy, ω) into per-leg stride vectors
  - Unlocks crab-walking and motion along any heading; hexapods are naturally
    holonomic so this is low-risk
  - Localized to `swing_trajectory.c` (stride vector) and one field in
    `user_command.h`; lowest-effort visible win in this section
  - Ref: standard omnidirectional legged locomotion; e.g. Gonzalez de Santos,
    Garcia & Estremera (2006), *Quadrupedal Locomotion: An Introduction to the
    Control of Four-legged Robots*, Springer (body-velocity → foot-stride mapping)

#### Tier 2 — Needs v2 IMU (small code once hardware lands)
- [ ] **Body-attitude stabilization (auto-leveling on slopes)**
  - Use IMU roll/pitch to add per-leg z offsets keeping the body level on
    uneven terrain; injected at the trajectory→WBC stage (the roll/pitch
    `pose_mode` TODO at `swing_trajectory.c:143`)
  - Ref: Saranli, Buehler & Koditschek (2001), "RHex: A Simple and Highly Mobile Hexapod Robot", *IJRR* 20(7):616-631
  - Ref: Pratt et al. (2001), "Virtual Model Control: An Intuitive Approach for Bipedal Locomotion", *IJRR* 20(2):129-143

- [ ] **Inertial stumble / elevator reflex**
  - On unexpected IMU pitch/roll spike (or a swing leg failing to find ground),
    trigger an elevator reflex: lift higher and re-place
  - Ref: Cruse, Kindermann, Schumm, Dean & Schmitz (1998), "Walknet — a biologically inspired network to control six-legged walking", *Neural Networks* 11(7-8):1435-1447

- [ ] **Self-righting / fall recovery (third priority)**
  - Detect an inverted or fallen state from the IMU, then run a scripted (or
    optimized) flip-back-over routine to return to a walkable posture
  - Lower priority than auto-leveling and reflexes; great demo once those land
  - Ref: Saranli, Buehler & Koditschek (2001), "RHex: A Simple and Highly Mobile Hexapod Robot", *IJRR* 20(7):616-631
  - Ref: Saranli & Koditschek (2002), "Template-based control of the RHex hexapod", *IEEE ICRA*

#### Tier 3 — Needs v2 per-leg current sensing (flagship research feature)
- [ ] **Tegotae — decentralized force-feedback gait emergence**
  - Each leg modulates its own oscillator phase by the ground reaction force it
    feels (using per-servo current draw as a GRF proxy); speed-dependent gaits
    and tripod↔wave transitions emerge with no central gait selection
  - Plugs the force term directly into the CPG engine (Tier 1)
  - Ref: Owaki & Ishiguro (2017), "A Minimal Model Describing Hexapedal Interlimb Coordination: The Tegotae-Based Approach", *Frontiers in Neurorobotics* 11:29
  - Ref: Owaki, Kano, Nagasawa, Tero & Ishiguro (2013), "Simple robot suggests physical interlimb communication is essential for quadruped walking", *J. Royal Society Interface* 10:20120669

- [ ] **Walknet — full decentralized coordination rules (lowest priority)**
  - The complete set of ~6 local leg-to-leg coordination rules from which insect
    gaits emerge with no central scheduler; kinematic cousin of Tegotae (which is
    force-based)
  - **Likely cannot run concurrently with Tegotae** — both are decentralized
    interlimb-coordination schemes competing for the same role. Treat as an
    **A/B-toggle alternative** to Tegotae (config-selectable), not an addition
  - Lowest priority in this section; keep on the list as a research comparison
  - Ref: Cruse, Kindermann, Schumm, Dean & Schmitz (1998), "Walknet — a biologically inspired network to control six-legged walking", *Neural Networks* 11(7-8):1435-1447

#### Needs Analysis — open questions before scheduling
These are promising but not yet scoped; each needs analysis of how it fits with
the items above before it earns a tier/priority.
- [ ] **Static stability margin + support-polygon-aware foot placement**
  - Compute the support polygon from stance-leg positions and keep the CoM
    projection inside it with a margin; bias stance / delay lift-off when the
    margin shrinks
  - **Open question:** implications and how it interacts with the CPG, Tegotae,
    and holonomic motion — is it a safety gate layered on top, or a placement
    planner that competes with them? Needs analysis before scheduling
  - Ref: McGhee & Frank (1968), "On the stability properties of quadruped creeping gaits", *Mathematical Biosciences* 3:331-351
  - Ref: Hirose, Tsukagoshi & Yoneda (1998), "Normalized Energy Stability Margin", *IEEE ICRA*

- [ ] **Manipulability- / singularity-aware posture optimization**
  - Choose body height and stance width to keep each leg's Jacobian
    well-conditioned (away from joint limits and singularities)
  - **Open question:** how it composes with auto-leveling, holonomic motion, and
    the gait engine (shared posture authority). Needs analysis before scheduling
  - Ref: Yoshikawa (1985), "Manipulability of Robotic Mechanisms", *IJRR* 4(2):3-9

- [ ] **Phase-resetting sensory entrainment into the CPG**
  - Feed contact events back to reset oscillator phase so the gait rhythm
    entrains to the terrain; the proven bridge between feedforward CPG and
    feedback reflexes
  - **Open question:** whether/how it fits alongside Tegotae's phase modulation
    (both inject sensory feedback into the same oscillators). Needs analysis,
    depends on the CPG engine existing first
  - Ref: Aoi & Tsuchiya (2005), "Locomotion control of a biped robot using nonlinear oscillators", *Autonomous Robots* 19(3):219-232

---

## 🔧 Existing Code TODOs

### Configuration & Storage
- [x] **NVS Storage Foundation** (`hex_config_manager`, `hex_motion_limits`, `robot_config`)
  - Implemented namespace-based NVS persistence for `system`, `joint_cal`, `leg_geom`, and `motion_lim`
  - Implemented boot-time load/default/migration pipeline in config manager
  - Implemented KPP runtime consumption of `motion_lim` during `kpp_init` with fail-fast behavior

- [x] **NVS Scope Expansion**
  - Extend persisted namespaces to `servo_map`, `controller`, `gait` and `wifi` as needed
  - Add explicit coverage tracking for remaining parameter schemas

- [x] **Per-leg Configuration** (`robot_config.c`)
  - Replace geometry/mount/stance hardcoded defaults with storage-loaded values when `leg_geom` is loaded
  - Consider per-leg geometry differences (mirrors, tolerances)
  - Remove remaining fallback paths once strict source-of-truth policy is finalized (`joint_cal` still has fallback defaults)

### Motion Control System
- [ ] **Advanced Motion Modes** (`kpp_system.h`)
  - Add MOTION_MODE_FAST for quick reactions
  - Add MOTION_MODE_EMERGENCY for fall recovery
  - Add mode_transition_time for multi-mode support
  - Implement fast mode limits
  - Implement emergency mode limits

- [ ] **Swing Trajectory Improvements** (`swing_trajectory.c`, `swing_trajectory.h`)
  - Make swing trajectory parameters configurable via Kconfig or runtime config
  - Make max turn angle configurable (currently hardcoded to 0.4 rad)
  - Make turn direction configurable
  - Add simple body roll/pitch offsets when pose_mode is active
  - Add yaw (wz) coupling to bias per-leg x/y for turning
  - Consider exposing trajectory parameters via config or calibration struct
  - Add C1/C2-continuous swing/stance blending to reduce velocity/acceleration discontinuities at phase boundaries
  - Add minimum-jerk or quintic foot trajectory mode for smoother liftoff/touchdown
  - Add configurable easing windows around liftoff/touchdown events

- [ ] **Gait Scheduler Enhancements** (`gait_scheduler.c`)
  - Consider separate forward/turning components and modulate phase rate
  - Replace current groupings with well-defined groupings and exact phase windows per gait
  - Add commanded-speed slew limiting so phase/frequency changes are gradual
  - Add gait transition blending (tripod/ripple/wave) to avoid abrupt group switching

### Control & Safety
- [ ] **Error Handling & Safety** (`whole_body_control.c`)
  - Add error signaling so robot_control can engage a safe stop
  - Implement comprehensive safety mechanisms
  - Add system health monitoring
  - Add arming checks (controller link valid, config loaded, telemetry channel healthy, basic power checks)
  - Add parameter-change safe-apply flow with timeout revert for risky live tuning updates

- [x] **Controller Configuration** (`controller.c`)
  - Make DEAD_BAND configurable via Kconfig or runtime configuration
  - Add controller parameter tuning interfaces

### Future Sensor Integration
- [ ] **Coordinate Frame Transformations** (`kpp_config.h`)
  - Add coordinate frame transformation parameters
  - Implement sensor fusion framework

- [ ] **Sensor Fusion Parameters** (`kpp_config.h`)
  - Design sensor fusion architecture for IMU/force sensors
  - Implement sensor data processing pipeline
  - Add sensor calibration procedures

---

## 🖥️ Hexapod Configurator Portal (Betaflight-inspired)

### Core Infrastructure
- [ ] **Communication Protocol**
  - Design JSON-RPC or MessagePack-based protocol for ESP32 ↔ Configurator
  - Implement WebSocket connection for real-time communication
  - Add command/response handling with error codes
  - Create parameter read/write API endpoints
  - Implement telemetry streaming protocol
  - Split channels into command/control plane and telemetry plane to avoid tuning latency under load
  - Add topic-based telemetry subscription with configurable publish rates

- [ ] **Web Application Framework**
  - Create React/Vue.js based configurator interface
  - Design responsive UI for desktop and tablet use
  - Implement WebSocket client for ESP32 communication
  - Add configuration state management
  - Create reusable UI components for parameter tuning

### Configuration Pages & Features

#### 🦿 **Leg Configuration Tab**
- [ ] Individual leg parameter tuning
  - Per-leg servo angle offsets and limits
  - Leg geometry parameters (coxa, femur, tibia lengths)
  - Servo direction and calibration settings
  - Real-time leg position visualization (3D model)
  - "Test Leg Movement" controls for each leg

#### ⚙️ **Motion Control Tab**
- [ ] Gait pattern configuration
  - Gait type selection (tripod, wave, ripple, custom)
  - Step height, length, and timing parameters
  - Swing trajectory curve parameters
  - Body height and stance width settings
  - Real-time gait visualization

#### 🎮 **Controller Settings Tab**
- [ ] Input device configuration
  - FlySky controller channel mapping and calibration
  - ESP-NOW controller pairing and setup
  - Dead zones and sensitivity curves
  - Control mode switching (manual/autonomous)
  - Input signal monitoring and diagnostics

#### 🧭 **Sensors & IMU Tab**
- [ ] Sensor calibration and monitoring
  - IMU calibration wizard (accelerometer, gyroscope)
  - Touch sensor threshold settings per leg
  - Real-time sensor data visualization
  - Terrain leveling algorithm parameters
  - Sensor fusion weight settings

#### 🔧 **System Parameters Tab**
- [ ] Core system configuration
  - KPP motion limits (velocity, acceleration, jerk)
  - Safety parameters and emergency stops
  - Power management settings
  - Debug logging levels
  - System health monitoring

#### 📊 **Telemetry & Monitoring Tab**
- [ ] Real-time robot status
  - Live 3D robot visualization showing current pose
  - Servo positions and load monitoring
  - Battery voltage and current consumption
  - System temperature monitoring
  - Error logs and diagnostic information
  - Per-joint plots: commanded vs limited angle/velocity/acceleration
  - Gait plots: phase, support/swing state, foot target XYZ per leg
  - Control-loop timing charts (dt jitter, loop overrun counters)

#### 💾 **Configuration Management Tab**
- [ ] Profile and backup management
  - Save/load configuration profiles
  - Export/import settings to/from files
  - Factory reset functionality
  - Configuration versioning and diff viewing
  - Automatic backup before major changes

### Advanced Features
- [ ] **Live Tuning & Testing**
  - Real-time parameter adjustment with immediate effect
  - "Safe Mode" with automatic revert after timeout
  - Parameter validation and bounds checking
  - Undo/redo functionality for parameter changes
  - Batch parameter updates

- [ ] **Calibration Wizards**
  - Automated servo calibration sequence
  - IMU calibration step-by-step guide
  - Leg geometry measurement assistant
  - Gait optimization wizard
  - Touch sensor threshold auto-calibration

- [ ] **Diagnostic Tools**
  - Servo health check and performance testing
  - Communication link quality monitoring
  - System performance profiling
  - Error code lookup and troubleshooting guide
  - Log file viewer and analysis
  - Blackbox-style ring buffer capture with event markers (failsafe, IK error, timeout)
  - Export log bundles for offline plotting/comparison between tuning sessions
  - Pre/post event capture windows for fault analysis

### ESP32 Firmware Support
- [ ] **Parameter Storage System**
  - Extend NVS storage to support all configurable parameters
  - Implement parameter validation and bounds checking
  - Add parameter change notification system
  - Create parameter schema/metadata system
  - Implement atomic parameter updates

- [ ] **Web Server & API**
  - Implement HTTP server for configurator hosting
  - Add WebSocket server for real-time communication
  - Create REST API for parameter access
  - Implement file upload/download for configurations
  - Add OTA update support through configurator

- [ ] **Telemetry System**
  - Real-time data streaming to configurator
  - Configurable telemetry rates and data selection
  - Data logging to SD card or flash memory
  - Remote logging capabilities
  - Performance metrics collection
  - Binary telemetry encoding (MessagePack/CBOR) to reduce bandwidth and latency vs text logs
  - Per-topic rate limiting and backpressure handling to protect control-loop timing
  - Runtime telemetry on/off and topic filtering without reboot

---

## 📋 Implementation Priority

### Phase 1: Foundation (High Priority)
1. FlySky controller debugging and reconnection
2. Electronics/connector improvements
3. Expand NVS coverage for remaining namespaces (foundation is complete)
4. Error handling and safety mechanisms
5. **Basic configurator infrastructure** (communication protocol, web framework)
6. **High-rate WiFi telemetry path** (non-serial observability for tuning)

### Phase 2: Enhanced Control & Configuration (Medium Priority)
1. **Core configurator pages** (Leg Config, Motion Control, System Parameters)
2. IMU integration and terrain leveling
3. Touch sensors implementation
4. Advanced motion modes (Fast/Emergency)
5. Swing trajectory improvements
6. **Configuration management and calibration wizards**
7. **Gait transition smoothing + phase/frequency slew limiting**
8. **Bio-inspired locomotion Tier 1** (Wilson continuum → CPG oscillators → min-impact swing → holonomic/lateral `vy`) — pure software, no new hardware

### Phase 3: Advanced Features (Lower Priority)
1. **Advanced configurator features** (telemetry, diagnostics, live tuning)
2. ESP-NOW controller development
3. Jetson Nano integration
4. Dual camera system
5. Computer vision capabilities
6. Advanced sensor fusion
7. **Blackbox-style event logging and offline analysis workflow**
8. **Bio-inspired locomotion Tier 2/3** (IMU attitude stabilization + reflexes; self-righting/flip recovery; Tegotae force-feedback gaits once per-leg current sensing exists. Walknet is an A/B alternative to Tegotae, lowest priority)
9. **Locomotion "Needs Analysis" items** (static stability margin, singularity-aware posture, CPG phase-resetting entrainment) — scope and fit before scheduling

---

## 📝 Notes
- Current system has comprehensive KPP (Kinematic Pose Position) implementation
- Debug infrastructure is in place for development and tuning
- Motion limiting and safety systems are partially implemented
- FlySky controller was previously working but needs debugging for signal stability

---

*Last updated: June 16, 2026*

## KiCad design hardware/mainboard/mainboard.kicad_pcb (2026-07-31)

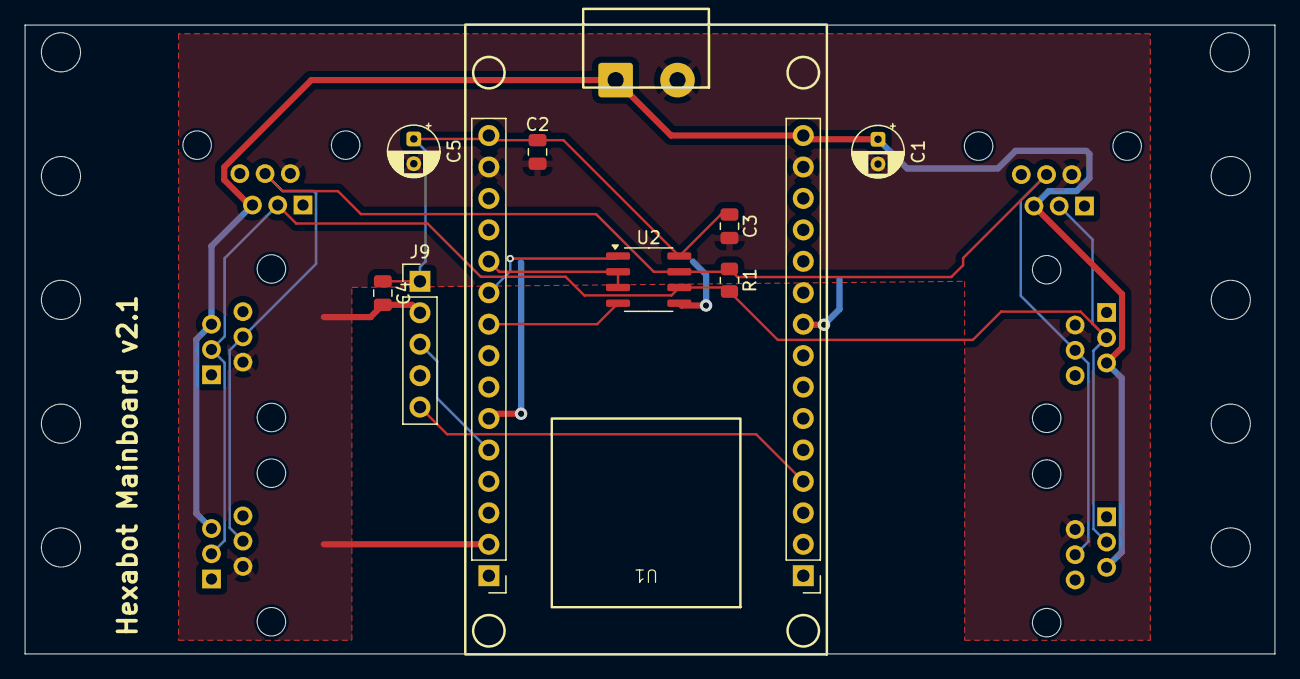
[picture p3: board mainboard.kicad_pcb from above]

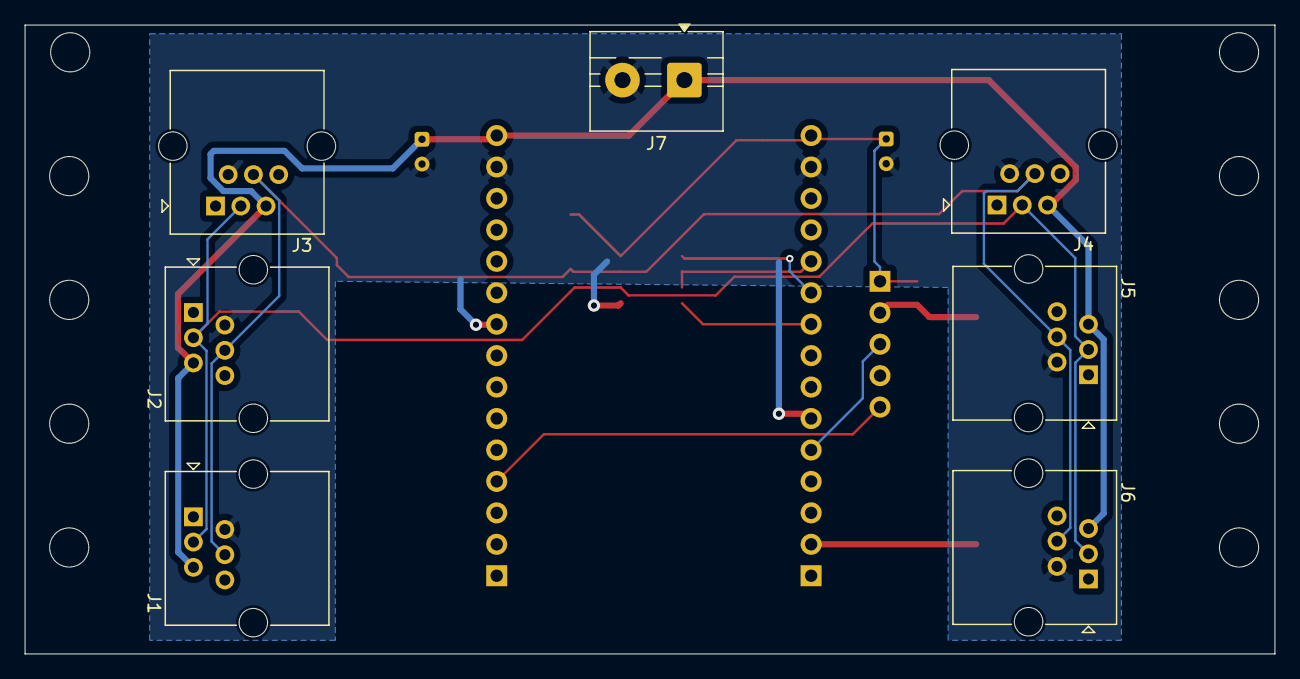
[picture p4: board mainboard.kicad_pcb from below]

Board: 2 copper layers, 101.0 x 50.8 mm, 16 parts (7 on the bottom side), 10 nets.

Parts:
C1, C5: 10uF; CP_Radial_D4.0mm_P2.00mm
C2, C3, C4: 100nF; C_0805_2012Metric
J1: LEG1_RJ11; RJ25_Wayconn_MJEA-660X1_Horizontal
J2: LEG2_RJ11; RJ25_Wayconn_MJEA-660X1_Horizontal
J3: LEG3_RJ11; RJ25_Wayconn_MJEA-660X1_Horizontal
J4: LEG4_RJ11; RJ25_Wayconn_MJEA-660X1_Horizontal
J5: LEG5_RJ11; RJ25_Wayconn_MJEA-660X1_Horizontal
J6: LEG6_RJ11; RJ25_Wayconn_MJEA-660X1_Horizontal
J7: SBEC_5V_IN; TerminalBlock_MaiXu_MX126-5.0-02P_1x02_P5.00mm
J9: IMU_I2C; PinHeader_1x05_P2.54mm_Vertical
R1: 120; R_0805_2012Metric
U1: ESP32-WROOM-32D; ESP32_Dev_Board
U2: SP3485CN; SOIC-8_3.9x4.9mm_P1.27mm

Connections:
+3.3V: C2.1, C3.1, C4.1, C5.1, J9.1, U1.3 (V3.3), U2.8 (VCC)
+5V: C1.1, J1.5, J2.5, J3.5, J4.5, J5.5, J6.5, J7.1, U1.2 (VIN)
ESP_RXD: U1.25 (IO16), U2.1 (RO)
ESP_TXD: U1.27 (IO17), U2.4 (DI)
GND: C1.2, C2.2, C3.2, C4.2, C5.2, J1.2, J2.2, J3.2, J4.2, J5.2, J6.2, J7.2, J9.2, U1.1 (GND), U1.15 (GND), U1.38 (GND), U1.39 (GND), U2.5 (GND)
IMU_INT: J9.5, U1.10 (IO34)
IMU_SDA: J9.3, U1.42 (IO21)
RS485_A: J1.3, J2.3, J3.3, J4.3, J5.3, J6.3, R1.2, U2.6 (A)
RS485_B: J1.4, J2.4, J3.4, J4.4, J5.4, J6.4, R1.1, U2.7 (B)
RS485_DE: U1.24 (IO4), U2.2 (~RE), U2.3 (DE)

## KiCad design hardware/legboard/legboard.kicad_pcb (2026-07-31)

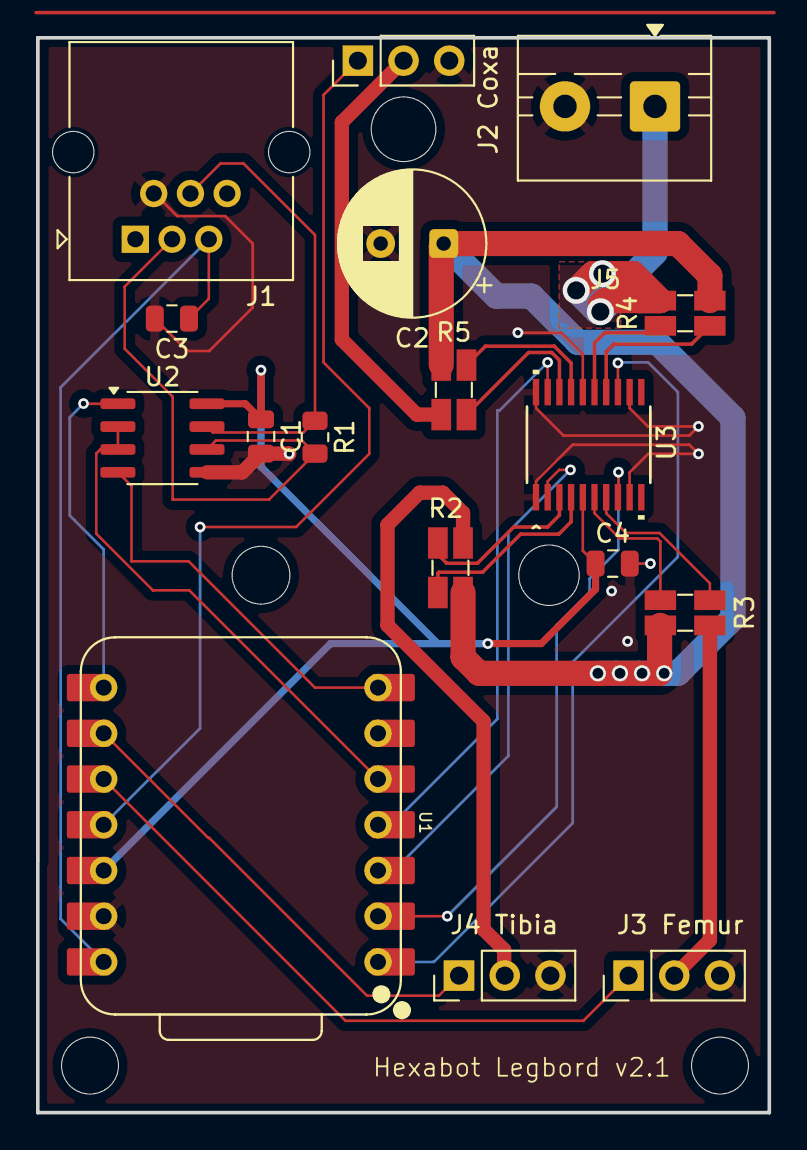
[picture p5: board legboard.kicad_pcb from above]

Board: 2 copper layers, 40.6 x 59.7 mm, 17 parts (0 on the bottom side), 28 nets.

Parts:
C1, C3, C4: 100nF; C_0805_2012Metric
C2: 470uF; CP_Radial_D8.0mm_P3.50mm
J1: UPLINK_RJ11; RJ25_Wayconn_MJEA-660X1_Horizontal
J2 Coxa: COXA; PinHeader_1x03_P2.54mm_Vertical
J3 Femur: FEMUR; PinHeader_1x03_P2.54mm_Vertical
J4 Tibia: TIBIA; PinHeader_1x03_P2.54mm_Vertical
J5: SERVO_PWR_IN; TerminalBlock_MaiXu_MX126-5.0-02P_1x02_P5.00mm
R1: 120 (DNP); R_0805_2012Metric
R2, R3, R4, R5: 0.01; R_Shunt_Ohmite_LVK12
U1: XIAO-RP2040; XIAO-RP2040-DIP
U2: SP3485CN; SOIC-8_3.9x4.9mm_P1.27mm
U3: INA4181A3IPWR; PW20_TEX

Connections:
+3.3V: C1.1, C4.1, U1.12 (3V3), U2.8 (VCC), U3.5 (VS)
+5V: C3.1, J1.5, U1.14 (VBUS)
+6V: C2.1, R2.1, R3.1, R4.4, R5.1
+6V_COXA: J2 Coxa.2, R5.4
+6V_FEMUR: J3 Femur.2, R3.4
+6V_IN: J5.1, R4.1
+6V_TIBIA: J4 Tibia.2, R2.4
COXA_PWM: J2 Coxa.1, U1.11 (P3_D10_MOSI)
COXA_SN: R5.3, U3.18 (IN-4)
COXA_SP: R5.2, U3.17 (IN+4)
FEMUR_PWM: J3 Femur.1, U1.10 (P4_D9_MISO)
FEMUR_SN: R3.3, U3.7 (IN-2)
FEMUR_SP: R3.2, U3.6 (IN+2)
GND: C1.2, C2.2, C3.2, C4.2, J1.2, J2 Coxa.3, J3 Femur.3, J4 Tibia.3, J5.2, U1.13 (GND), U2.5 (GND), U3.1 (REF1), U3.9 (REF2), U3.12 (REF3), U3.16 (GND), U3.20 (REF4)
ITOT_SN: R4.3, U3.14 (IN-3)
ITOT_SP: R4.2, U3.15 (IN+3)
I_COXA_SENSE: U1.4 (P29_A3_D3), U3.19 (OUT4)
I_FEMUR_SENSE: U1.2 (P27_A1_D1), U3.8 (OUT2)
I_TIBIA_SENSE: U1.3 (P28_A2_D2), U3.2 (OUT1)
I_TOTAL_SENSE: U1.1 (P26_A0_D0), U3.13 (OUT3)
RP_RXD: U1.8 (P1_D7_RX), U2.1 (RO)
RP_TXD: U1.7 (P0_D6_TX), U2.4 (DI)
RS485_A: J1.3, R1.2, U2.6 (A)
RS485_B: J1.4, R1.1, U2.7 (B)
RS485_DE: U1.5 (P6_SDA_D4), U2.2 (~RE), U2.3 (DE)
TIBIA_PWM: J4 Tibia.1, U1.9 (P2_D8_SCK)
TIBIA_SN: R2.3, U3.3 (IN-1)
TIBIA_SP: R2.2, U3.4 (IN+1)

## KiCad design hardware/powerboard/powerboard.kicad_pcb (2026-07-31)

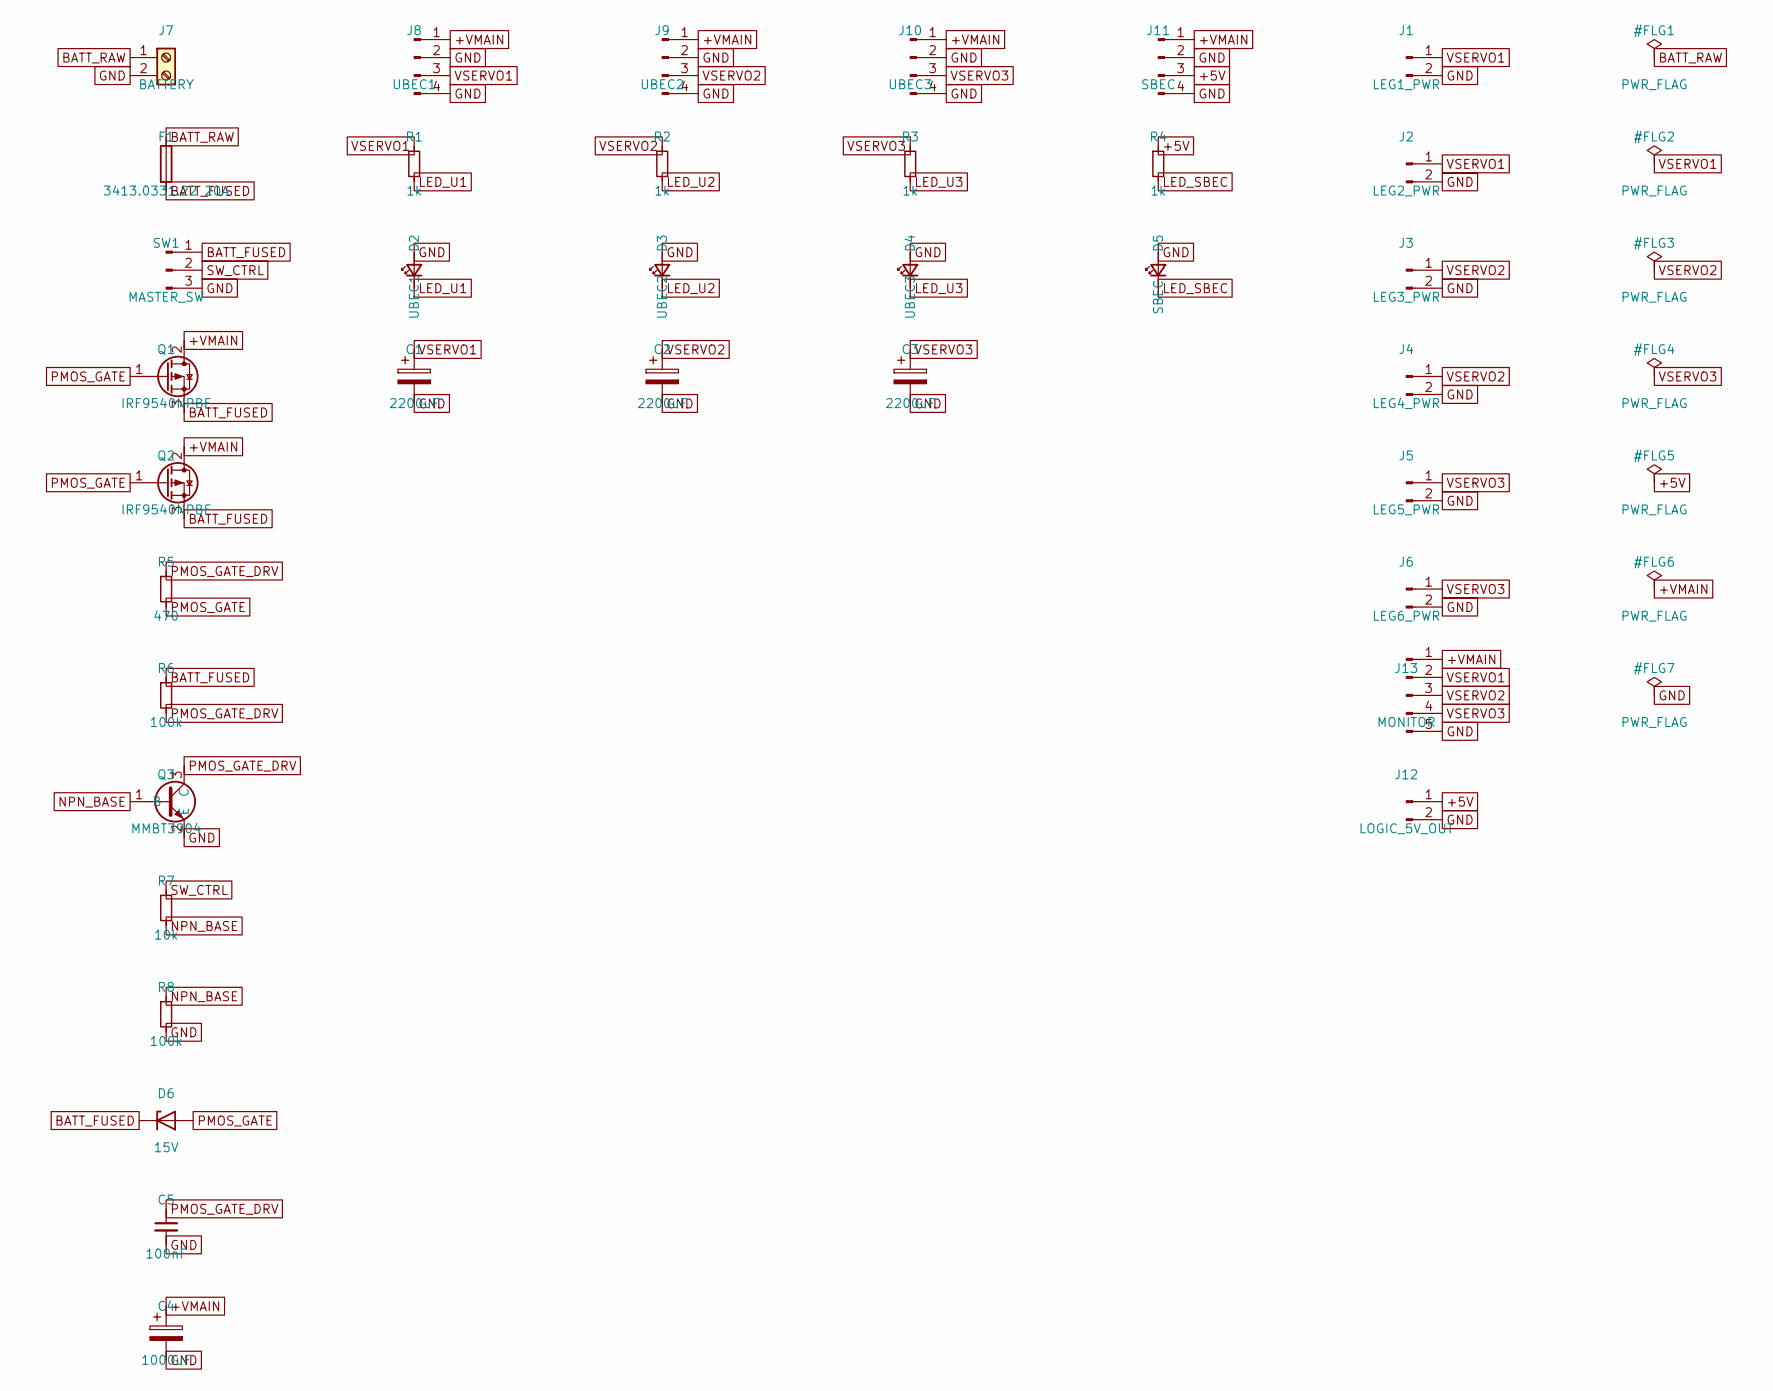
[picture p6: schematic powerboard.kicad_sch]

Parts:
C1, C2, C3: 2200uF; CP_Radial_D13.0mm_P5.00mm
C4: 1000uF; CP_Radial_D8.0mm_P3.80mm
C5: 100nF; C_0805_2012Metric
D2: UBEC1; LED_0805_2012Metric
D3: UBEC2; LED_0805_2012Metric
D4: UBEC3; LED_0805_2012Metric
D5: SBEC; LED_0805_2012Metric
D6: 15V; D_0805_2012Metric
F1: 3413.0331.22 20A; Fuse_1206_3216Metric
J1: LEG1_PWR; TerminalBlock_MaiXu_MX126-5.0-02P_1x02_P5.00mm
J2: LEG2_PWR; TerminalBlock_MaiXu_MX126-5.0-02P_1x02_P5.00mm
J3: LEG3_PWR; TerminalBlock_MaiXu_MX126-5.0-02P_1x02_P5.00mm
J4: LEG4_PWR; TerminalBlock_MaiXu_MX126-5.0-02P_1x02_P5.00mm
J5: LEG5_PWR; TerminalBlock_MaiXu_MX126-5.0-02P_1x02_P5.00mm
J6: LEG6_PWR; TerminalBlock_MaiXu_MX126-5.0-02P_1x02_P5.00mm
J7: BATTERY; SolderWire-1.5sqmm_1x02_P7.8mm_D1.7mm_OD3.9mm
J8: UBEC1; SolderWirePad_4x01_SMD_3x4mm
J9: UBEC2; SolderWirePad_4x01_SMD_3x4mm
J10: UBEC3; SolderWirePad_4x01_SMD_3x4mm
J11: SBEC; SolderWirePad_4x01_SMD_3x4mm
J12: LOGIC_5V_OUT; PinHeader_1x02_P2.54mm_Vertical
J13: MONITOR; PinHeader_1x05_P2.54mm_Vertical
Q1, Q2: IRF9540NPBF; TO-220-3_Vertical
Q3: MMBT3904; SOT-23
R1, R2, R3, R4: 1k; R_0805_2012Metric
R5: 470; R_0805_2012Metric
R6, R8: 100k; R_0805_2012Metric
R7: 10k; R_0805_2012Metric
SW1: MASTER_SW; SW_Slide_SPDT_Straight

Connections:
+5V: J11.3, J12.1, R4.1
+VMAIN: C4.1, J8.1, J9.1, J10.1, J11.1, J13.1, Q1.2 (D), Q2.2 (D)
BATT_FUSED: D6.1 (K), F1.2, Q1.3 (S), Q2.3 (S), R6.1, SW1.1
BATT_RAW: F1.1, J7.1
GND: C1.2, C2.2, C3.2, C4.2, C5.2, D2.2 (A), D3.2 (A), D4.2 (A), D5.2 (A), J1.2, J2.2, J3.2, J4.2, J5.2, J6.2, J7.2, J8.2, J8.4, J9.2, J9.4, J10.2, J10.4, J11.2, J11.4, J12.2, J13.5, Q3.2 (E), R8.2, SW1.3
LED_SBEC: D5.1 (K), R4.2
LED_U1: D2.1 (K), R1.2
LED_U2: D3.1 (K), R2.2
LED_U3: D4.1 (K), R3.2
NPN_BASE: Q3.1 (B), R7.2, R8.1
PMOS_GATE: D6.2 (A), Q1.1 (G), Q2.1 (G), R5.2
PMOS_GATE_DRV: C5.1, Q3.3 (C), R5.1, R6.2
SW_CTRL: R7.1, SW1.2
VSERVO1: C1.1, J1.1, J2.1, J8.3, J13.2, R1.1
VSERVO2: C2.1, J3.1, J4.1, J9.3, J13.3, R2.1
VSERVO3: C3.1, J5.1, J6.1, J10.3, J13.4, R3.1

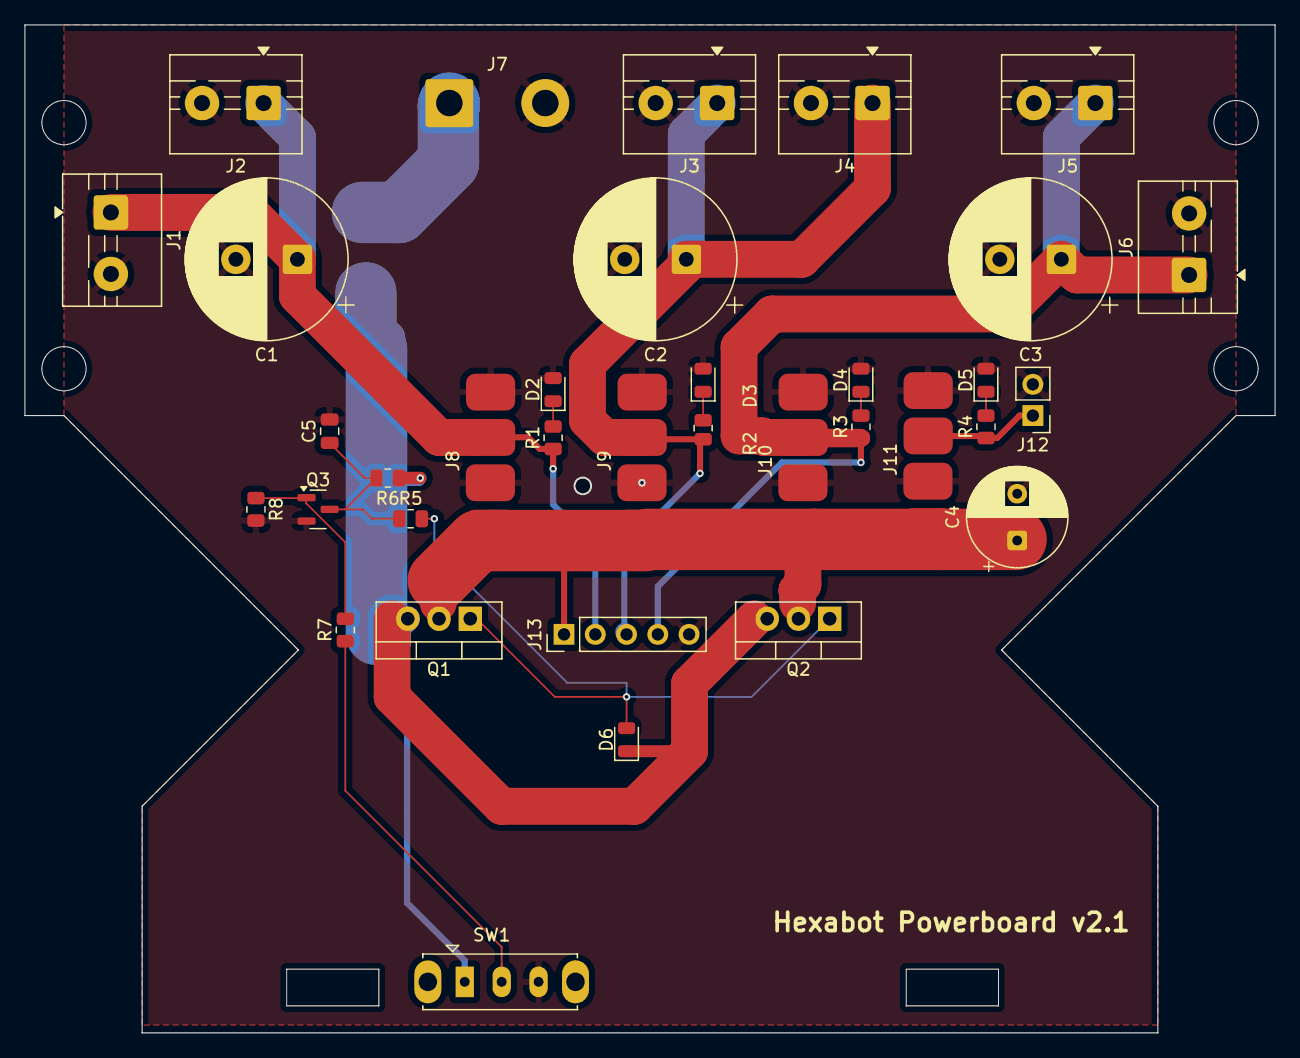
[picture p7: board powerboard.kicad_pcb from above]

Board: 2 copper layers, 101.6 x 81.9 mm, 36 parts (1 on the bottom side), 16 nets.

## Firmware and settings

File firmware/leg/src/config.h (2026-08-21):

// Compile-time configuration for the RP2040 LegBoard firmware.
//
// Pin map is from docs/architecture/HARDWARE_AND_MECHANICS.md.
// The "Pn" labels in that table are RP2040 GPIO numbers; "D4" is the XIAO
// silkscreen label for GP6. VERIFY against the LegBoard schematic before
// trusting on hardware.

#ifndef HEX_LEG_CONFIG_H
#define HEX_LEG_CONFIG_H

#include <stdint.h>

// --- Joints --------------------------------------------------------------
#define NUM_JOINTS 3
enum { JOINT_COXA = 0, JOINT_FEMUR = 1, JOINT_TIBIA = 2 };

// --- RP2040 GPIO assignments (XIAO RP2040) -------------------------------
// RS485 / UART0
#define PIN_UART_TX   0   // GP0  -> SP3485 DI
#define PIN_UART_RX   1   // GP1  <- SP3485 RO
#define PIN_RS485_DE  6   // GP6 (XIAO D4) -> SP3485 DE/RE direction control

// Servo PWM
#define PIN_PWM_COXA   3  // GP3
#define PIN_PWM_FEMUR  4  // GP4
#define PIN_PWM_TIBIA  2  // GP2

// Current sense (ADC). RP2040 ADC inputs: GP26=ADC0 .. GP29=ADC3.
//
// Physical wiring (hardware/legboard/legboard_sch.py) does NOT follow
// coxa/femur/tibia pin order: I_TOTAL_SENSE->GP26, I_FEMUR_SENSE->GP27,
// I_TIBIA_SENSE->GP28, I_COXA_SENSE->GP29 -- confirmed on real hardware
// 2026-08-02 (calibrating "coxa" moved the "femur" reading, etc., a clean
// one-position rotation). ADC_CH_* below is the stable LOGICAL channel
// numbering used everywhere external (CURRAW?/CURCAL, tools/leg_configurator.py,
// s_channel_name in calib.cpp) -- it intentionally keeps coxa=1/femur=2/
// tibia=3 regardless of physical pin order. current.cpp's
// kAdcPhysicalInput[] maps each logical channel to the RP2040 ADC input
// number that must actually be selected; PIN_ISENSE_* below is only used to
// enable the 4 GPIOs for ADC use (order doesn't matter for that part).
#define PIN_ISENSE_TOTAL  26  // A0 / ADC0 -- I_TOTAL_SENSE
#define PIN_ISENSE_FEMUR  27  // A1 / ADC1 -- I_FEMUR_SENSE
#define PIN_ISENSE_TIBIA  28  // A2 / ADC2 -- I_TIBIA_SENSE
#define PIN_ISENSE_COXA   29  // A3 / ADC3 -- I_COXA_SENSE
#define ADC_CH_TOTAL  0
#define ADC_CH_COXA   1
#define ADC_CH_FEMUR  2
#define ADC_CH_TIBIA  3

// --- RS485 link ----------------------------------------------------------
#define RS485_BAUD            1000000UL
#define UART_INSTANCE_INDEX   0          // uart0 (TX=GP0, RX=GP1)

// --- Control loop --------------------------------------------------------
// Internal interpolation / servo update rate (independent of the RS485 rate).
// HARDWARE_AND_MECHANICS.md specifies 500-1000 Hz.
//
// This is a software poll against micros() in main.cpp's loop() (no hardware
// timer/interrupt), so the achieved rate isn't guaranteed by construction --
// measure it with LOOPSTAT? (loopstat.h/.cpp) if in doubt. Measured on real
// hardware 2026-08-03: 1000 -> 998 Hz and 2000 -> ~1995 Hz, both with huge
// headroom (loop_hz ~178-195k); 10000 -> ~9790 Hz, a real ~2% shortfall,
// because the control step body itself costs ~82us and starts eating into
// the 100us window. Ceiling is somewhere between 2 kHz and 10 kHz -- 1 kHz
// and 2 kHz are both essentially free.
#define CONTROL_RATE_HZ   1000U
#define CONTROL_PERIOD_US (1000000U / CONTROL_RATE_HZ)

// --- Servo PWM -----------------------------------------------------------
#define SERVO_PWM_FREQ_HZ   50
#define SERVO_PERIOD_US     20000   // 1 / 50 Hz

// --- Stored parameter defaults (see RS485_PROTOCOL.md "Stored Parameters")
// Runtime params live in RAM at these defaults; the ESP32 re-applies any
// non-default values on recovery. They are NOT persisted to flash.
#define DEFAULT_MOVE_DURATION_MS     10
#define DEFAULT_WATCHDOG_TIMEOUT_MS  500
#define INTERP_MODE_LINEAR  0
#define INTERP_MODE_CUBIC   1
#define DEFAULT_INTERP_MODE  INTERP_MODE_LINEAR  // prove LINEAR first; CUBIC via P03

// Joint hard-limit defaults (degrees). Wide enough to allow full intended
// range until calibration narrows them. Master sends limits as 0.1-deg units
// via params P04..P09.
#define DEFAULT_JOINT_MIN_DEG  -90.0f
#define DEFAULT_JOINT_MAX_DEG   90.0f

// --- Servo calibration defaults (per servo) ------------------------------
// Calibration lives on the leg (the ESP32 cannot supply PWM calibration).
// Compile-time defaults now; shaped for flash persistence later.
// 500-2500us matches this servo's actual rated pulse width (per its datasheet
// label) -- the previous 1000-2000us was the generic "SG90-style" hobby-servo
// assumption, which only exercised a narrow middle slice of this servo's real
// travel (measured ~19-51 deg actual for a commanded 60/-90 deg on leg 1 coxa
// before this fix). See docs/development/LEG_CALIBRATION.md.
#define DEFAULT_PWM_MIN_US      500
#define DEFAULT_PWM_NEUTRAL_US  1500
#define DEFAULT_PWM_MAX_US      2500
#define DEFAULT_ANGLE_MIN_DEG   -90.0f
#define DEFAULT_ANGLE_MAX_DEG    90.0f

// --- Current sensing -----------------------------------------------------
#define ADC_RESOLUTION_BITS  12
#define ADC_MAX_COUNT        ((1 << ADC_RESOLUTION_BITS) - 1)
#define ADC_VREF_MV          3300
// INA4181 gain and shunt are board-specific. DEFAULT_ISENSE_MA_PER_MV is the
// fallback per-channel scale used until a channel has been calibrated via
// CURCAL (see calib.cpp / tools/current_calibration); DEFAULT_ISENSE_OFFSET_MA
// is the matching fallback offset.
#define DEFAULT_ISENSE_MA_PER_MV   1.0f
#define DEFAULT_ISENSE_OFFSET_MA   0.0f
#define NUM_CURRENT_CHANNELS 4  // total, coxa, femur, tibia (ADC_CH_* order)

// Smoothing for the *reported* (calibrated) current -- current_sample()
// runs at CONTROL_RATE_HZ (1 kHz) but the ESP32 only pulls each leg roughly
// every 10 ms (100 Hz, docs/interfaces/RS485_PROTOCOL.md "Timing Budget"),
// so without this the telemetry value would just be whichever single 1 kHz
// sample happened to land at poll time. Two selectable strategies (set over
// USB, see calib.cpp CURFILT -- current.h current_set_filter_mode()/
// current_set_boxcar_n()), because per-servo current spikes are also the
// intended touchdown-detection signal (docs/architecture/HARDWARE_AND_MECHANICS.md)
// and heavier averaging blunts/delays them:
//   EMA (default) -- alpha=0.4 gives a ~2-sample (~2 ms) time constant at
//     1 kHz: real noise reduction while still surfacing most of a spike
//     within a couple of samples, well inside one 10 ms poll interval.
//     alpha is tunable (0 < alpha <= 1): lower = more smoothing/latency,
//     1.0 = unfiltered (equivalent to reporting the raw 1 kHz sample).
//   BOXCAR -- a flat N-sample moving average (default N=10, i.e. the ~10 ms
//     poll interval). Trades more latency for stronger, uniform noise
//     reduction: a touchdown spike may only become clearly visible about
//     one window late (e.g. ~20 ms at N=10 instead of ~10 ms).
// CURRAW?'s raw mV/counts (calib.cpp) are never filtered -- calibration
// wants the true instantaneous ADC reading. Both the mode and its
// parameter (alpha or N) are persisted -- see persist_get/set_current_filter().
#define CURRENT_FILTER_EMA     0
#define CURRENT_FILTER_BOXCAR  1
#define DEFAULT_CURRENT_FILTER_MODE  CURRENT_FILTER_EMA
#define DEFAULT_CURRENT_EMA_ALPHA 0.4f
#define CURRENT_BOXCAR_MAX_N   32  // upper bound on the ring-buffer window
#define DEFAULT_CURRENT_BOXCAR_N 10

// --- Flash persistence -----------------------------------------------------
// Two independent EEPROM.h partitions (see persist.cpp): a tiny "identity"
// partition (leg address) and a tiny "calib" partition (current-sense
// scale/offset), each with its own magic/version so one can be reset or
// reformatted without touching the other.
// NOTE: this must never collide with the old pre-partition combined-record
// layout (magic "LEG1"=0x4C454731, versions 1-2, leg_addr at the same
// offset) -- a board previously flashed with that firmware would otherwise
// have its old address bytes misread as valid new-format identity data and
// skip reinitializing to the "uncalibrated" default. Use a distinct magic.
#define PERSIST_IDENTITY_MAGIC    0x4C454944UL  // "LEID" (distinct from old "LEG1")
#define PERSIST_IDENTITY_VERSION  1
#define PERSIST_CALIB_MAGIC       0x43414C31UL  // "CAL1"
#define PERSIST_CALIB_VERSION     5  // v5: added per-joint sign inversion

// 0 is not a valid RS485 address (the protocol uses 1-6) and marks an
// unassigned/uncalibrated board. It is only ever set by ADDR <1-6> during
// bring-up; the board blinks its status LED until then (see status_led.*).
#define DEFAULT_LEG_ADDR 0

// --- Status LED ------------------------------------------------------------
// XIAO RP2040 onboard RGB LED, red channel. Common-anode: LOW = on. Blinks
// at 2 Hz (toggle every 250 ms) while uncalibrated (leg_addr == 0); off once
// a real address has been set.
#define PIN_STATUS_LED_R          17
#define STATUS_LED_ACTIVE_LOW     1
#define STATUS_LED_BLINK_HALF_PERIOD_US  250000UL

#endif // HEX_LEG_CONFIG_H

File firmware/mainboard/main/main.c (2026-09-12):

/*
 *
 * License: Apache-2.0
 */

#include <stdint.h>
#include "esp_timer.h"
#include "freertos/FreeRTOS.h"
#include "freertos/task.h"
#include "esp_log.h"
#include "driver/mcpwm_prelude.h"
#include "leg.h"
#include <math.h>
#include "gait_scheduler.h"
#include "swing_trajectory.h"
#include "whole_body_control.h"
#include "robot_control.h"
#include "robot_config.h"
#include "user_command.h"
#include "controller.h"
#include "controller_flysky_ibus.h"
#include <string.h>
#include "wifi_ap.h"
#include "controller_bt_classic.h"
#include "controller_wifi_tcp.h"
#include "kpp_system.h"
#include "config_manager_runtime_api.h"
#include "config_ns_system_api.h"
#include "config_ns_controller_api.h"
#include "config_ns_wifi_api.h"
#include "config_ns_gait_api.h"
#include "rpc_commands.h"
#include "rs485_master.h"

static const char *TAG = "main";

// --- Gait Framework Main Loop ---
void gait_framework_main(void *arg)
{
    gait_scheduler_t scheduler;
    swing_trajectory_t trajectory;
    whole_body_cmd_t cmds;
    user_command_t ucmd; // current command
    user_command_t prev_cmd; // previous command for change detection
    memset(&ucmd, 0, sizeof(ucmd));
    memset(&prev_cmd, 0, sizeof(prev_cmd));

    // Initialize KPP (Kinematic Pose Position) system
    kinematic_state_t kpp_state;
    motion_limits_t motion_limits;
    ESP_ERROR_CHECK(kpp_init(&kpp_state, &motion_limits));
    ESP_LOGI(TAG, "KPP system initialized with motion limiting enabled");

    // Initialize gait framework modules
    const gait_config_t* gait_cfg = config_get_gait();
    if (!gait_cfg) {
        ESP_LOGE(TAG, "Gait namespace unavailable");
        return;
    }

    gait_scheduler_init(&scheduler, gait_cfg->cycle_time_s);
    scheduler.duty_factor_min = gait_cfg->duty_factor_min;
    scheduler.duty_factor_max = gait_cfg->duty_factor_max;
    swing_trajectory_init(&trajectory, gait_cfg->step_length_m, gait_cfg->clearance_height_m);
    trajectory.y_range_m = gait_cfg->y_range_m;
    trajectory.z_min_m = gait_cfg->z_min_m;
    trajectory.z_max_m = gait_cfg->z_max_m;
    trajectory.max_yaw_per_cycle_rad = gait_cfg->max_yaw_per_cycle_rad;
    trajectory.turn_direction = gait_cfg->turn_direction;

    // Nominal loop cadence. dt is measured per-iteration below (see loop) so the
    // gait clock tracks wall time even if a cycle overruns; this is only the
    // scheduling period fed to vTaskDelayUntil.
    const TickType_t loop_period_ticks = pdMS_TO_TICKS(10); // 100 Hz target
    ESP_LOGI(TAG, "gait loop: FreeRTOS tick %d Hz (portTICK_PERIOD_MS=%d), period %d tick(s); task core %d prio %d",
             (int)configTICK_RATE_HZ, (int)portTICK_PERIOD_MS, (int)loop_period_ticks,
             (int)xPortGetCoreID(), (int)uxTaskPriorityGet(NULL));
    if (loop_period_ticks < 1) {
        ESP_LOGW(TAG, "tick rate too low for a sub-10ms period; loop will run slower than 100 Hz");
    }

    TickType_t last_wake_ticks = xTaskGetTickCount();
    int64_t prev_cycle_us = esp_timer_get_time();

    // --- Loop-rate diagnostics ---------------------------------------------
    // Accumulate per-iteration timing and dump a summary once every 5 s:
    //   - busy:   compute time of one iteration (locomotion -> actuation), no wait
    //   - period: wall time between consecutive iteration starts (actual cadence)
    // plus the RS485 bus master's own sweep/transaction counters, so leg update
    // rate and main-loop rate can be compared side by side.
    const int64_t DIAG_WINDOW_US = 5 * 1000 * 1000;
    int64_t diag_window_start_us = esp_timer_get_time();
    int64_t diag_prev_iter_us    = diag_window_start_us;
    uint32_t diag_iters          = 0;
    int64_t  diag_busy_total_us  = 0;
    int64_t  diag_period_total_us = 0;
    uint32_t diag_busy_min_us    = UINT32_MAX, diag_busy_max_us   = 0;
    uint32_t diag_period_min_us  = UINT32_MAX, diag_period_max_us = 0;

    // Per-phase breakdown of the "busy" time, so a slow stage can be spotted.
    enum { PH_POLL, PH_SCHED, PH_SWING, PH_WBC, PH_KPPLIM, PH_EXEC, PH_KPPUPD, PH_COUNT };
    static const char *const ph_name[PH_COUNT] = {
        "poll", "sched", "swing", "wbc", "kpp_lim", "exec", "kpp_upd"
    };
    int64_t  ph_total_us[PH_COUNT] = {0};
    uint32_t ph_max_us[PH_COUNT]   = {0};
    #define DIAG_PHASE(idx, stmt) do {                                  \
        int64_t _p0 = esp_timer_get_time();                             \
        stmt;                                                           \
        int64_t _pd = esp_timer_get_time() - _p0;                       \
        ph_total_us[idx] += _pd;                                        \
        if (_pd > ph_max_us[idx]) ph_max_us[idx] = (uint32_t)_pd;       \
    } while (0)

    while (1) {
        int64_t iter_start_us = esp_timer_get_time();

        // Measured timestep since the previous iteration. Clamped so a one-off
        // stall (WiFi association, logging burst) can't fast-forward the gait or
        // blow up the KPP velocity/accel estimates via a huge 1/dt.
        float dt = (float)(iter_start_us - prev_cycle_us) / 1e6f;
        prev_cycle_us = iter_start_us;
        if (dt < 0.001f) dt = 0.001f;
        if (dt > 0.05f)  dt = 0.05f;

        // Copy current to previous then poll new
        prev_cmd = ucmd;
        DIAG_PHASE(PH_POLL, user_command_poll(&ucmd));
        if (!controller_user_command_equal(&prev_cmd, &ucmd, 1e-2f)) {
            ESP_LOGI(TAG, "User command: vx=%.2f, vy=%.2f, wz=%.2f, z_target=%.2f, y_offset=%.2f gait=%d enable=%d pose=%d terrain=%d step_scale=%.2f",
                    ucmd.vx, ucmd.vy, ucmd.wz, ucmd.z_target, ucmd.y_offset, ucmd.gait, ucmd.enable, ucmd.pose_mode, ucmd.terrain_climb, ucmd.step_scale);
        }

        whole_body_cmd_t limited_cmds;
        // Update gait scheduler (leg phases)
        DIAG_PHASE(PH_SCHED, gait_scheduler_update(&scheduler, dt, &ucmd));
        // Generate swing trajectories for legs using scheduler + command
        DIAG_PHASE(PH_SWING, swing_trajectory_generate(&trajectory, &scheduler, &ucmd));
        // Compute joint commands from trajectories
        DIAG_PHASE(PH_WBC, whole_body_control_compute(&trajectory, &cmds));
        // KPP: Apply motion limiting for smooth servo operation
        DIAG_PHASE(PH_KPPLIM, kpp_apply_limits(&kpp_state, &motion_limits, &cmds, &limited_cmds, dt));
        // Send limited commands to robot
        DIAG_PHASE(PH_EXEC, robot_execute(&limited_cmds));
        // CRITICAL FIX: Update state estimation based on ORIGINAL commands, not limited ones
        // This breaks the feedback loop that was causing oscillations
        DIAG_PHASE(PH_KPPUPD, kpp_update_state(&kpp_state, &cmds, dt));  // original commands for state estimation

        // --- Loop-rate diagnostics: accumulate this iteration ---
        int64_t iter_busy_us = esp_timer_get_time() - iter_start_us;
        int64_t iter_period_us = iter_start_us - diag_prev_iter_us;
        diag_prev_iter_us = iter_start_us;
        diag_iters++;
        diag_busy_total_us += iter_busy_us;
        if (iter_busy_us < diag_busy_min_us) diag_busy_min_us = (uint32_t)iter_busy_us;
        if (iter_busy_us > diag_busy_max_us) diag_busy_max_us = (uint32_t)iter_busy_us;
        if (diag_iters > 1) { // first period spans init, skip it
            diag_period_total_us += iter_period_us;
            if (iter_period_us < diag_period_min_us) diag_period_min_us = (uint32_t)iter_period_us;
            if (iter_period_us > diag_period_max_us) diag_period_max_us = (uint32_t)iter_period_us;
        }

        if (iter_start_us - diag_window_start_us >= DIAG_WINDOW_US) {
            // Stats keep accumulating every iteration; only the 5 s dump below is
            // gated off. Emitting these lines pushes ~300 bytes over the 115200
            // console UART, which blocks this task for 10-20 ms and shows up as a
            // period spike. Flip DIAG_LOG_ENABLED to 1 for a bring-up session.
            #define DIAG_LOG_ENABLED 0

            // Drain the bus counters regardless, so they don't grow unbounded.
            rs485_master_stats_t bus;
            rs485_master_get_stats(&bus);

            if (DIAG_LOG_ENABLED) {
                float win_s = (iter_start_us - diag_window_start_us) / 1e6f;
                uint32_t pcount = (diag_iters > 1) ? (diag_iters - 1) : 1;
                ESP_LOGI(TAG,
                    "loop: %.1f Hz (%lu iters/%.1fs) | busy avg %.2f max %.2f min %.2f ms | period avg %.2f max %.2f min %.2f ms",
                    diag_iters / win_s, (unsigned long)diag_iters, win_s,
                    diag_busy_total_us / 1000.0f / diag_iters,
                    diag_busy_max_us / 1000.0f, diag_busy_min_us / 1000.0f,
                    diag_period_total_us / 1000.0f / pcount,
                    diag_period_max_us / 1000.0f, diag_period_min_us / 1000.0f);

                if (bus.sweeps > 0) {
                    uint32_t ok = 0, to = 0;
                    for (int i = 0; i < NUM_LEGS; ++i) { ok += bus.leg_ok[i]; to += bus.leg_timeout[i]; }
                    ESP_LOGI(TAG,
                        "bus: %.1f leg-updates/s (%lu sweeps) | sweep avg %.2f max %.2f min %.2f ms | txn avg %.0f max %lu min %lu us | ok %lu timeout %lu",
                        bus.sweeps / win_s, (unsigned long)bus.sweeps,
                        bus.sweep_total_us / 1000.0f / bus.sweeps,
                        bus.sweep_max_us / 1000.0f, bus.sweep_min_us / 1000.0f,
                        bus.txn_count ? (float)bus.txn_total_us / bus.txn_count : 0.0f,
                        (unsigned long)bus.txn_max_us, (unsigned long)bus.txn_min_us,
                        (unsigned long)ok, (unsigned long)to);
                    if (to > 0) {
                        ESP_LOGW(TAG,
                            "bus timeouts per leg: L1=%lu L2=%lu L3=%lu L4=%lu L5=%lu L6=%lu",
                            (unsigned long)bus.leg_timeout[0], (unsigned long)bus.leg_timeout[1],
                            (unsigned long)bus.leg_timeout[2], (unsigned long)bus.leg_timeout[3],
                            (unsigned long)bus.leg_timeout[4], (unsigned long)bus.leg_timeout[5]);
                    }
                } else {
                    ESP_LOGW(TAG, "bus: RS485 master completed no sweeps this window (task stalled?)");
                }

                char phbuf[192];
                int off = 0;
                for (int p = 0; p < PH_COUNT; ++p) {
                    off += snprintf(phbuf + off, sizeof(phbuf) - off, "%s%s %.2f/%.2f",
                                    p ? " | " : "", ph_name[p],
                                    ph_total_us[p] / 1000.0f / diag_iters,
                                    ph_max_us[p] / 1000.0f);
                    if (off >= (int)sizeof(phbuf)) break;
                }
                ESP_LOGI(TAG, "phase avg/max ms: %s", phbuf);
            }
            (void)bus;

            diag_window_start_us = iter_start_us;
            diag_iters = 0;
            diag_busy_total_us = diag_period_total_us = 0;
            diag_busy_min_us = diag_period_min_us = UINT32_MAX;
            diag_busy_max_us = diag_period_max_us = 0;
            memset(ph_total_us, 0, sizeof(ph_total_us));
            memset(ph_max_us, 0, sizeof(ph_max_us));
        }

        // Hold a fixed cadence. If the cycle overran the period, xTaskDelayUntil
        // returns immediately (pdFALSE) without blocking -- in that case yield one
        // tick anyway so the idle task runs and the task watchdog stays happy.
        if (xTaskDelayUntil(&last_wake_ticks, loop_period_ticks) == pdFALSE) {
            last_wake_ticks = xTaskGetTickCount();
            vTaskDelay(1);
        }
    }
}

void app_main(void)
{
    // Initialize configuration manager first
    ESP_LOGI(TAG, "Starting hexapod application...");
    esp_err_t err = config_manager_init();
    if (err != ESP_OK) {
        ESP_LOGE(TAG, "Failed to initialize configuration manager: %s", esp_err_to_name(err));
        return;
    }
    
    // Get system configuration
    const system_config_t* sys_config = config_get_system();
    ESP_LOGI(TAG, "System config loaded: robot_id=%s, robot_name=%s", 
             sys_config->robot_id, sys_config->robot_name);
    ESP_LOGI(TAG, "Safety settings: emergency_stop=%s, voltage_min=%.2fV", 
             sys_config->emergency_stop_enabled ? "enabled" : "disabled",
             sys_config->safety_voltage_min);
    
    // Joint calibration system is now active and will be used by robot_control
    ESP_LOGI(TAG, "Joint calibration configuration loaded and ready for robot control");
    
    // Apply startup delay from configuration
    if (sys_config->startup_delay_ms > 0) {
        ESP_LOGI(TAG, "Applying startup delay: %lu ms", (unsigned long)sys_config->startup_delay_ms);
        vTaskDelay(pdMS_TO_TICKS(sys_config->startup_delay_ms));
    }
    
    // Initialize RPC system
    rpc_init();

    // Load WiFi namespace-backed options for AP and TCP controller transport.
    const wifi_config_namespace_t* wifi_ns_cfg = config_get_wifi();
    if (!wifi_ns_cfg) {
        ESP_LOGE(TAG, "WiFi namespace unavailable");
        return;
    }

    wifi_ap_options_t ap_opts = {
        .mode = (wifi_ap_ssid_mode_e)wifi_ns_cfg->ap_ssid_mode,
        .fixed_prefix = wifi_ns_cfg->ap_fixed_prefix,
        .fixed_ssid = wifi_ns_cfg->ap_fixed_ssid,
        .password = wifi_ns_cfg->ap_password,
        .channel = (uint8_t)wifi_ns_cfg->ap_channel,
        .max_clients = (uint8_t)wifi_ns_cfg->ap_max_clients,
    };
    
    // Bring up WiFi AP early so that network-based controller drivers or diagnostics
    // can connect even if later initialization stalls.
    if (!wifi_ap_init_with_options(&ap_opts)) {
        ESP_LOGE(TAG, "Failed to initialize WiFi AP from namespace configuration");
        return;
    }
    
    // Initialize robot configuration (namespace-backed; fail fast on invalid state)
    err = robot_config_init_default();
    if (err != ESP_OK) {
        ESP_LOGE(TAG, "Failed to initialize robot configuration: %s", esp_err_to_name(err));
        return;
    }

    // V2: start the RS485 bus master. It owns UART2 and polls the six LegBoards
    // in its own task, independent of the 100 Hz motion loop. Actuation writes
    // desired joint angles into its command buffer (non-blocking).
    err = rs485_master_init();
    if (err != ESP_OK) {
        ESP_LOGE(TAG, "Failed to initialize RS485 master: %s", esp_err_to_name(err));
        return;
    }
    
    // Initialize the primary controller from configuration namespaces.
    const controller_config_namespace_t* controller_cfg = config_get_controller();
    if (!controller_cfg) {
        ESP_LOGE(TAG, "Controller namespace unavailable");
        return;
    }

    controller_config_t ctrl_cfg = {
        .driver_type = controller_cfg->driver_type,
        .task_stack = (int)controller_cfg->task_stack,
        .task_prio = (int)controller_cfg->task_priority,
        .driver_cfg = NULL,
        .driver_cfg_size = 0,
    };

    // Assign driver-specific configuration if needed. static: their address is
    // stored in controller_core (g_cfg.driver_cfg) and read later by the driver
    // task; app_main returns once the tasks are spawned, so an auto (stack)
    // struct here would dangle.
    static controller_flysky_ibus_cfg_t flysky_cfg;
    static controller_wifi_tcp_cfg_t wifi_tcp_cfg;
    if (ctrl_cfg.driver_type == CONTROLLER_DRIVER_FLYSKY_IBUS) {
        flysky_cfg.uart_port = controller_cfg->flysky_uart_port;
        flysky_cfg.tx_gpio = controller_cfg->flysky_tx_gpio;
        flysky_cfg.rx_gpio = controller_cfg->flysky_rx_gpio;
        flysky_cfg.rts_gpio = controller_cfg->flysky_rts_gpio;
        flysky_cfg.cts_gpio = controller_cfg->flysky_cts_gpio;
        flysky_cfg.baud_rate = controller_cfg->flysky_baud_rate;
        ctrl_cfg.driver_cfg = &flysky_cfg;
        ctrl_cfg.driver_cfg_size = sizeof(flysky_cfg);
    } else if (ctrl_cfg.driver_type == CONTROLLER_DRIVER_WIFI_TCP) {
        wifi_tcp_cfg.listen_port = (uint16_t)wifi_ns_cfg->tcp_listen_port;
        wifi_tcp_cfg.connection_timeout_ms = (uint16_t)wifi_ns_cfg->tcp_connection_timeout_ms;
        ctrl_cfg.driver_cfg = &wifi_tcp_cfg;
        ctrl_cfg.driver_cfg_size = sizeof(wifi_tcp_cfg);
    }
    
    controller_init(&ctrl_cfg);

    // Launch the primary controller's input driver. controller_init() only
    // stores config -- without an explicit launch here the FlySky iBUS UART
    // reader task never starts, so no stick input reaches locomotion. (The
    // dispatch that used to do this lived in user_command_init(), which
    // nothing calls.) Only the iBUS driver is wired up here; WIFI_TCP is
    // handled by the always-on secondary interface below.
    if (ctrl_cfg.driver_type == CONTROLLER_DRIVER_FLYSKY_IBUS) {
        controller_driver_init_flysky_ibus(&ctrl_cfg);
    }

    // ALWAYS initialize WiFi TCP controller for RPC commands (separate from primary controller)
    // This provides network-based diagnostics and control regardless of primary controller type
    if (ctrl_cfg.driver_type != CONTROLLER_DRIVER_WIFI_TCP) {
        ESP_LOGI(TAG, "Initializing WiFi TCP controller as secondary RPC interface");
        controller_wifi_tcp_cfg_t wifi_rpc_cfg = {
            .listen_port = (uint16_t)wifi_ns_cfg->tcp_listen_port,
            .connection_timeout_ms = (uint16_t)wifi_ns_cfg->tcp_connection_timeout_ms,
        };
        controller_config_t wifi_ctrl_cfg = {
            .driver_type = CONTROLLER_DRIVER_WIFI_TCP,
            .task_stack = controller_cfg->task_stack, // Use same stack size as primary controller
            .task_prio = 8,  // Lower priority than primary controller
            .driver_cfg = &wifi_rpc_cfg,
            .driver_cfg_size = sizeof(wifi_rpc_cfg),
        };
        controller_driver_init_wifi_tcp(&wifi_ctrl_cfg);
    }
    
    // Run the 100 Hz locomotion loop in its own task pinned to APP_CPU (core 1).
    // Priority 14: above the controller driver (~8), below the RS485 bus master
    // (prio 15, also core 1 -- its per-leg read window is timing-critical) and
    // below the WiFi/BT stack on core 0. Previously this ran inline in the prio-1
    // main task, where every other subsystem preempted it -- the measured loop
    // rate was ~45 Hz with 40-90 ms period spikes and ~11 ms "busy" time.
    BaseType_t gait_ok = xTaskCreatePinnedToCore(
        gait_framework_main, "gait", 8192, NULL, 14, NULL, 1);
    if (gait_ok != pdPASS) {
        ESP_LOGE(TAG, "Failed to create gait task");
        return;
    }
    // app_main returns; the main task self-deletes and FreeRTOS keeps running.
}

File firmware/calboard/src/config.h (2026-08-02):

// Compile-time configuration for the current-sensor calibration adapter
// board (bench tool only — not a robot board). See
// hardware/calboard/calboard_sch.py for the schematic this pin map must
// match, and firmware/leg/README.md / tools/current_calibration/ for how
// this board is used.

#ifndef HEX_CALBOARD_CONFIG_H
#define HEX_CALBOARD_CONFIG_H

#include <stdint.h>

// --- Channels --------------------------------------------------------------
#define NUM_CHANNELS 3
enum { CH_COXA = 0, CH_FEMUR = 1, CH_TIBIA = 2 };

// --- RP2040 GPIO assignments (XIAO RP2040) ---------------------------------
// PWM decode inputs — wired to the LegBoard's servo signal pin (J2/J3/J4
// pin 1) instead of a real servo.
#define PIN_PWMIN_COXA   0  // GP0 (XIAO D6)
#define PIN_PWMIN_FEMUR  1  // GP1 (XIAO D7)
#define PIN_PWMIN_TIBIA  2  // GP2 (XIAO D8)

// Rail-voltage readback (ADC). RP2040 ADC inputs: GP26=ADC0 .. GP28=ADC2.
// GP29/ADC3 is left spare.
#define PIN_VSENSE_COXA   26  // ADC0
#define PIN_VSENSE_FEMUR  27  // ADC1
#define PIN_VSENSE_TIBIA  28  // ADC2
#define ADC_CH_COXA   0
#define ADC_CH_FEMUR  1
#define ADC_CH_TIBIA  2

// Two daisy-chained 74HC595 shift registers drive all 3*4=12 MOSFET gates
// from 3 GPIO. Bit order: channel 0 (coxa) bits 0-3, channel 1 (femur) bits
// 4-7, channel 2 (tibia) bits 8-11 — see ladder.cpp.
#define PIN_SR_SER    4  // GP4 (XIAO D9)  -> 74HC595 SER (serial data)
#define PIN_SR_SRCLK  3  // GP3 (XIAO D10) -> 74HC595 SRCLK (shift clock)
#define PIN_SR_RCLK   6  // GP6 (XIAO D4)  -> 74HC595 RCLK (latch)

// --- Servo PWM decode -------------------------------------------------------
// Matches DEFAULT_PWM_MIN_US/DEFAULT_PWM_MAX_US in firmware/leg/src/config.h
// — the LegBoard's default (uncalibrated) servo pulse range.
#define PWM_DECODE_MIN_US   1000
#define PWM_DECODE_MAX_US   2000
#define LADDER_STEPS        15  // non-zero steps per channel (4-bit ladder)

// --- Resistor ladder (per channel) ------------------------------------------
// Binary-weighted resistor legs, each switched to GND by its own MOSFET.
// Effective resistance for a bit-code 0-15 is the parallel combination of
// active legs (see ladder.cpp); with these values a bit's conductance
// roughly doubles per step, so current scales close to linearly with code.
//
// PLACEHOLDER VALUES — reviewed for a modest bench-test current range
// (~27 mA to ~490 mA at 6V) to keep worst-case single-leg dissipation
// low(ish); R4 alone still dissipates ~1.6W at 6V and needs a real power
// resistor (TO-220 / 2512 chip, not 0805). MUST be re-checked against the
// actual servos' expected current draw and resistor power ratings before
// this board is fabricated — see hardware/calboard/calboard_sch.py.
#define LADDER_R1_OHM  220.0f  // bit 0 (weakest)
#define LADDER_R2_OHM  100.0f  // bit 1
#define LADDER_R3_OHM   47.0f  // bit 2
#define LADDER_R4_OHM   22.0f  // bit 3 (strongest)

// --- ADC / voltage divider ---------------------------------------------------
#define ADC_RESOLUTION_BITS  12
#define ADC_MAX_COUNT        ((1 << ADC_RESOLUTION_BITS) - 1)
#define ADC_VREF_MV          3300
// Divider from the (up to ~6V) branch rail down into the RP2040's 3.3V ADC
// range: VSENSE_DIVIDER_RATIO = R_bottom / (R_top + R_bottom). Tune once the
// schematic's actual divider resistors are chosen.
#define VSENSE_DIVIDER_RATIO  0.5f

#endif // HEX_CALBOARD_CONFIG_H

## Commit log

2026-07-31 Remove V1, flatten V2 directory structure to repo root
    V1 hardware/firmware/docs are pruned entirely; V2 content moves up from
    firmware/v2, hardware/v2, docs/v2 to firmware/, hardware/, docs/ since
    it's now the only version in the repo. docs/common is folded into
    docs/configuration and docs/interfaces for the same reason.
    Fixes stale KiCad lib-table absolute paths (pointed at a different repo
    location entirely) to portable ${KIPRJMOD}-relative ones, merges
    hardware/v2/.gitignore's patterns into hardware/.gitignore, and updates
    all cross-references in READMEs, docs, firmware comments, and the
    hardware-schematics skill to the new flat paths.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
    [esp32_connector.kicad_pcb, esp32_connector.kicad_sch, hexapod.kicad_pcb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]
2026-07-31 hardware: restore R1 bus termination value to 100R
    mainboard_sch.py already specified 100R for the RS485 bus termination
    resistor (R1), but the committed mainboard.kicad_sch still had the old
    120R value — it hadn't been regenerated before the V1/V2 restructuring,
    and my earlier revert (to undo an accidental test-regeneration) put the
    stale 120R value back instead of the intended 100R. Confirmed against
    diff.txt (the pre-migration pending diff) and regenerated from source;
    no other change.
    [mainboard.kicad_sch]
2026-07-31 docs: note this repo continues the original Hexabot project
    Links back to the original hexapod repo and calls out that this repo
    (hexapod_v2) differs mainly in electronics architecture (distributed
    RP2040 leg controllers over RS485) plus new features like per-servo
    current sensing.
2026-07-31 Add CLAUDE.md with repo orientation for coding agents
    Covers the three-board architecture, firmware/hardware/docs layout,
    build/test commands, and a documentation map pointing to the right
    doc per topic rather than repeating their content.
2026-08-02 Add LegBoard identity/current-cal persistence, status LED, and configurator wizard
    - persist.cpp: split leg address and current-sense calibration into two
    independent EEPROM.h partitions with distinct magic/version, so resetting
    one doesn't touch the other. Leg address now defaults to 0 (uncalibrated)
    instead of 1.
    - status_led.cpp: blink the XIAO's onboard red LED at 2 Hz while
    uncalibrated (address 0), off once a real address is set; main.cpp now
    re-reads the persisted address every loop so this (and RS485 matching)
    updates immediately after ADDR, no reboot needed.
    - tools/leg_configurator.py: interactive wizard over the LegBoard's own USB
    console (no separate calibration boa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
    [config.h, main.cpp]
2026-08-02 Fix LegBoard current-sense ADC channel mapping, add calibration tooling
    Root cause: the coxa/femur/tibia current-sense pins are not wired in
    alphabetical A1/A2/A3 order (hardware/legboard/legboard_sch.py wires
    I_FEMUR_SENSE->A1, I_TIBIA_SENSE->A2, I_COXA_SENSE->A3), but firmware
    assumed the alphabetical mapping -- confirmed on real hardware by a clean
    one-position rotation while calibrating (attaching a resistor to "coxa"
    moved the "femur" reading, etc). current.cpp now compensates via
    kAdcPhysicalInput[], keeping the stable external channel numbering
    (CURRAW?/CURCAL, tools/*) untouched. HARDWARE_AND_MECHANICS.md's pin table
    had the same error and is corrected too.
    Also brings in the underl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
    [config.h]
2026-08-02 Add calboard bench current-calibration adapter, update foot model
    calboard is a bench-only tool (not part of the robot): a XIAO RP2040 +
    74HC595-driven resistor ladder that plugs into a LegBoard's servo
    connectors in place of real servos, giving known current loads for
    current-sense calibration. Adds hardware/calboard/ (schematic-as-code +
    generated KiCad project) and firmware/calboard/ (ladder step control, PWM
    capture to pick a load step, rail voltage readback, USB serial commands).
    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
    [calboard.kicad_pcb, calboard.kicad_sch, hexapod_v2.FCStd]
2026-08-02 Add selectable, tunable, persisted current-smoothing strategy on LegBoard
    RS485 pulls arrive roughly every 10 ms (100 Hz per leg) but current_sample()
    runs at 1 kHz, so without smoothing the reported current was just whichever
    single 1 kHz sample happened to land at poll time -- noisy. Two strategies,
    selectable and tunable over USB (calib.cpp CURFILT), because per-servo
    current spikes are also the intended touchdown-detection signal
    (docs/architecture/HARDWARE_AND_MECHANICS.md) and heavier averaging
    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
2026-08-02 Redesign leg_configurator calibration flow, add loop-rate instrumentation
    tools/leg_configurator.py: offset matters far more than scale for this
    hardware (INA4181 gain+shunt put scale theoretically near 1.0, ~0.97-0.99 in
    practice), so restructure the wizard around that:
    1. Measure zero-load offsets for all 4 channels in one shared step (one
    CURRAW? poll already reports all channels, so no more separate
    "disconnect for total" pass).
    2. Ask how far to take it: Enter/'n' (default) writes scale=1.0 with the
    measured offsets and stops; a number 0-2 uses it as the scale for every
    channel; 'y' goes on to the existing full per-channel resistor
    calibration, now reusing t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
    [config.h, main.cpp]
2026-08-21 Fix LegBoard servo PWM range, add mainboard RPC per-joint override
    - firmware/leg: DEFAULT_PWM_MIN_US/MAX_US were 1000/2000us (generic
    SG90-style assumption); the actual servos are rated 500-2500us. The old
    range only exercised a narrow middle slice of real travel -- measured
    ~19 deg actual for a commanded 60 deg on leg 1 coxa. Confirmed fixed by
    re-measuring the same commanded angle after the change (~60 deg actual).
    - firmware/mainboard: new RPC command `joint <leg> <coxa> <femur> <tibia>`
    (and `joint <leg> release`) drives one leg's three joints directly,
    bypassing gait/IK, for bring-up/diagnostics. Implemented as a manual
    per-leg override in hex_actuation's robot_execute()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
    [config.h]
2026-08-21 Make per-joint servo sign inversion calibratable, document the joint angle sign convention
    - firmware/leg: persist per-joint invert (+1/-1) alongside PWM neutral,
    loaded by servo_init()/servo_reload_invert() instead of the previous
    hardcoded +1. New calib.cpp USB commands INVERT?/INVERT <joint> <1|-1>.
    PERSIST_CALIB_VERSION 4->5 with an in-place migration that preserves
    existing PWM neutral calibration instead of wiping it on the version bump.
    - tools/leg_configurator.py: the gentle direction check now asks what
    direction each nudge produced, prints the expected direction per the IK
    model (femur/tibia only -- coxa's expected yaw is mount-rotation
    dependent), and offers to flip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
    [config.h]
2026-08-21 Address repo convention gaps in the joint/ik RPC diagnostic commands
    Per firmware/mainboard/AGENTS.md and .github/instructions/:
    - config-runtime-contract: replace the hardcoded RPC_JOINT_OVERRIDE_LIMIT_DEG
    constant with a clamp against the joint_cal namespace's per-leg/per-joint
    min_rad/max_rad (config_manager, not a locally-invented safety bound).
    This gives joint_cal its first real runtime consumer -- previously
    settable/persisted over RPC but read by nothing. Verified live: commanding
    120 deg now clamps to the configured 90 deg max instead of a flat 60.
    - component-readme-requirements: updated hex_rpc_core/README.md (new
    joint/ik commands, new hex_actuation/hex_robot_config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
2026-08-21 Correct default femur length to this hexapod version's actual 80mm
    config_domain_leg_geometry_defaults.c's default_len_femur was 0.088m,
    apparently carried over from an earlier hardware revision; this version's
    femur link is 80mm. Also corrected the stale value already persisted in
    this robot's leg_geom NVS for all six legs via `setpersist` (a compile-time
    default change alone doesn't affect a namespace that already has a
    persisted record -- confirmed live before fixing it).
2026-08-23 Fix servo PWM mapping to use a uniform rate, resolving the IK circle-tracing distortion
    Root cause of leg 1 tracing an ellipse/triangle instead of a circle: servo.cpp's
    angle->pulse mapping computed a *separate* rate on each side of the calibrated
    neutral (dividing available pulse headroom by a fixed 90deg per side), which
    silently assumes the servo's real response is asymmetric around wherever its
    calibrated center happens to land. A typical analog servo's pulse-to-angle
    response is actually uniform across its full rated range regardless of where
    manufacturing tolerance puts that center -- confirmed by prediction (leg 1's
    tibia, calibrated ~95us off the true 1500us midpoint, showing a growi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
    [robot_config.c]
2026-08-23 Add figure8 sweep mode; fix apparent update-rate jitter (script config, not hardware)
    - tools/ik_axis_test.py: new --mode figure8 (lemniscate of Gerono), same
    go-to-center/confirm/sweep/hold protocol as circle mode, --radius meaning
    half the figure's height. Shares --center/--plane/--loops/--release with
    circle mode.
    - Diagnosed reported "8-10Hz, very visible jitter": measured with a
    temporary firmware timestamp log (added and then removed -- this commit's
    only firmware change is an incidental leg_telemetry_t t = {0} safety fix
    left over from that instrumentation, avoiding a latent uninitialized-read
    when a poll fails) that the commanded target actually changed on the wire
    e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
2026-08-25 Improve leg bring-up tooling: auto-detect leg, add invert/center modes, redo direction check UX
    tools/ik.py, ik_axis_test.py, joint_direction_test.py: --leg now defaults
    to auto-detecting the first leg that responds on the bus instead of
    assuming leg 1, since during bring-up it's common for only one (not
    necessarily leg 1) leg to be wired up.
    tools/leg_configurator.py:
    - New --mode invert (query/set/toggle a joint's persisted INVERT sign
    alone) and --mode center (PWM neutral adjustment alone), so either can
    be touched up without running the whole servo wizard.
    - Reworked the gentle direction check: PWM <joint> <us> is a raw
    pulse-width write that bypasses INVERT entirely, so the old c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
2026-08-25 Standardize on LF line endings repo-wide via .gitattributes
    The repo's history had a genuine mix of LF and CRLF commits (14 tracked
    text files were committed with CRLF), which combined with local working
    copies picking up CRLF made `git status`/`git diff` show hundreds of
    files as changed on pure whitespace noise. Add .gitattributes
    (* text=auto eol=lf, with an explicit binary backstop for images/CAD/
    archives) so checkouts and commits are LF-normalized regardless of
    contributor OS/editor, and normalize the 14 previously-CRLF files to LF
    with no content change. Document the convention in CLAUDE.md and
    docs/development/README.md.
    [robot_config.c]
2026-09-07 Add leg bus enumeration tooling and pos RPC command
    `pos <leg 1-6>` on the mainboard RPC requests fresh joint-position
    telemetry from a LegBoard over RS485 and reports it back, re-arming the
    one-shot request each retry so the background poll loop can't clobber the
    flagged response before the handler reads it.
    tools/leg_scan.py drives that over WiFi TCP for legs 1-6 and prints which
    boards are answering on the bus plus each one's reported joint angles;
    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
2026-09-07 Leg configurator: reusable INVERT defaults; correct coxa length + tibia direction wording
    - Cache the confirmed INVERT sign per joint from a known-good leg and offer
    to seed the next leg's servo calibration with it (--save-invert-defaults
    / --apply-invert-defaults), still followed by the gentle direction check.
    - leg_geom default_len_coxa 0.068 -> 0.060 (caliper + CAD).
    - Fix swapped tibia straighten/curl wording in the direction check.
    Claude-Session: https://claude.ai/code/session_01XGrgQArHuc1qmtasbJpLkf
2026-09-09 mainboard: launch FlySky iBUS driver task in app_main
    controller_init() only stores the controller config; nothing ever started
    the iBUS UART reader task, so stick input never reached locomotion. Call
    controller_driver_init_flysky_ibus() explicitly when the primary driver is
    iBUS (WIFI_TCP is already handled by the always-on secondary interface).
    Claude-Session: https://claude.ai/code/session_01Di2hqgjcsYASavUS6C4pFF
2026-09-09 mainboard: run locomotion loop in a dedicated task; add loop/bus diagnostics
    The 100 Hz gait loop ran inline in the prio-1 main task, so every other
    subsystem preempted it: measured ~45 Hz with 40-90 ms period spikes and
    ~11 ms per-iteration "busy" time (mostly preemption, not compute). It also
    integrated the gait with a hardcoded dt=0.01 while the real period was
    ~22 ms, so the gait clock ran at ~0.45x realtime (very slow walk).
    Changes:
    - Spawn gait_framework_main() via xTaskCreatePinnedToCore (core 1, prio 14),
    above the controller driver and below the WiFi/BT stack. app_main returns.
    - Drive the loop with xTaskDelayUntil at a fixed 10 ms cadence (with a
    vTaskDelay(1) fallback on ove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
    [main.c]
2026-09-09 Ignore mesh exports (*.3mf) and Python bytecode caches
    *.3mf sits next to the already-ignored *.stl / *.step FreeCAD exports under
    hardware/models/. Add a repo-root .gitignore for __pycache__/ and *.pyc so
    the tools/ scripts stay clean.
    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
2026-09-09 Add LegBoard current-sensor calibration tool
    tools/current_calibration/ fits mA = scale*raw_mV + offset per INA4181
    channel (coxa/femur/tibia/total) against the calboard resistor ladder and
    pushes the coefficients to the LegBoard over its USB calibration serial
    (CURCAL, persisted to flash). Run once per board / hardware rev.
    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
2026-09-09 Add tools/rpc.py: send text RPC commands to the mainboard over WiFi TCP
    The mainboard's text RPC is only reachable over WiFi TCP / Bluetooth SPP,
    not the USB console. This wraps a socket connect + send/recv for one-shot
    (`python3 tools/rpc.py "get controller flysky_rx_gpio"`) or interactive use.
    See docs/interfaces/RPC_USER_GUIDE.md for the command set.
    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
2026-09-09 docs: document the platformio.ini ESP-IDF wrapper for the mainboard
    firmware/mainboard/ carries a committed platformio.ini (framework = espidf,
    src_dir = main) so `pio run` / `pio run -t upload` build the identical
    ESP-IDF firmware for anyone already set up with PlatformIO for the leg
    toolchain. idf.py stays canonical (docs, CI, and host tests assume it);
    PlatformIO just drives it underneath. Also fixes the mainboard build cwd in
    AGENTS.md (firmware/mainboard/, not repo root).
    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
2026-09-09 mainboard: default FlySky iBUS RX to GPIO5
    flysky_rx_gpio was 22, which is the I2C SCL net; a later "34" was a
    mis-identification -- package pin 34 on the ESP32 module is GPIO5, not
    GPIO34. GPIO5 is where the iBUS signal wire is actually tapped on the
    current build (board silk "D5"), confirmed receiving valid frames via
    firmware/mainboard_ibus_test. It is a bootstrap pin but iBUS idles high, so
    a powered receiver doesn't disturb boot.
    Update the controller namespace default and the header's fallback
    initializer (kept in sync), and document the pin + the GPIO5/GPIO34 mix-up
    in HARDWARE_AND_MECHANICS.md. A dedicated 3-pin receiver header is still a
    pending schematic change.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
    [config_domain_controller_defaults.c]
2026-09-09 hex_controller_driver_flysky_ibus: resync + checksum-validate iBUS frames
    The reader assumed each uart_read_bytes() returned a buffer starting on a
    frame boundary (data[0]==0x20, data[1]==0x40) and never checked the frame
    checksum. A UART read almost never lands on a boundary, so most frames were
    dropped and any that slipped through were unvalidated.
    Feed received bytes through a small resync state machine that locks onto the
    0x20 0x40 header, collects a full 32-byte frame, and accepts it only if the
    trailing u16 equals 0xFFFF - sum(first 30 bytes). Channel decode is
    unchanged (1000..2000 us -> -32768..32767).
    Claude-Session: https://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
2026-09-09 hardware/models: update FreeCAD source model
    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
    [hexapod_v2.FCStd]
2026-09-09 Ignore Claude Code local settings and firmware/leg/.claude/
    settings.local.json is per-user Claude Code state; the shared .claude/ config
    (rules, skills, agents) stays tracked.
    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
2026-09-09 mainboard: fix FlySky iBUS dying ~1s after boot (dangling driver config)
    Regression from moving the locomotion loop into its own task: app_main now
    returns once the tasks are spawned, which frees its stack. controller_core
    stores the driver_cfg pointer verbatim (no deep copy), and it pointed at
    app_main's stack-local controller_flysky_ibus_cfg_t. The iBUS task read a
    few valid frames at boot, then the freed stack was reused, cfg_drv->uart_port
    became garbage, and every uart_read_bytes() returned 0 -> "iBUS disconnected,
    entering failsafe" a second later.
    - flysky_task now deep-copies the driver config into its own storage instead
    of aliasing the caller's pointer (matching hex_controller_d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
    [main.c]
2026-09-09 gait: drop default cycle_time_s 1.5 -> 0.5 (~2 steps/s/leg at full speed)
    phase_rate at full stick is 1/cycle_time, so 1.5 s gave ~0.67 gait cycles/s
    = ~0.67 steps per leg per second, a crawl (~4.7 cm/s with the 0.07 m step).
    0.5 s gives ~2 steps/s/leg, the intended walking cadence.
    Note: only affects a fresh NVS. On a provisioned robot, apply with
    tools/rpc.py "set gait cycle_time_s 0.5" "save gait"
    and reboot (gait_scheduler_init reads cycle_time once at startup).
    Claude-Session: https://claude.ai/code/session_01Wno8VKs6iH8MdcYMbXpxtG
2026-09-09 kinematics: add body-frame IK helper + `foot` RPC, widen leg spread
    The gait's body->leg transform was only reachable through the full
    whole_body_control_compute() path, so a single leg couldn't be exercised
    with a known body-frame foot target during bring-up.
    - hex_kinematics: add leg_ik_solve_body() -- translate + rotate(-mount_yaw)
    + leg_ik_solve, optionally returning the intermediate leg-local target.
    - whole_body_control_compute(): use the shared helper instead of its own
    inline copy of the transform (single source of truth). Fix stale "Z down"
    comments -- the frame is Z up.
    - hex_rpc_core: add `foot <leg> <x> <y> <z>` -- body-frame counterpart of
    `ik`, runs the gait transform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
2026-09-10 locomotion: POC strafe on right stick horizontal (CH1)
    Repurpose the right-stick horizontal axis from a static lateral body
    shift (y_offset) to a strafe velocity command (vy). The step displacement
    in swing_trajectory is now a planar vector along heading (dir_x, dir_y)
    derived from (vx, vy), so pure vx walks forward, pure vy strafes, and a
    mix walks diagonally. Yaw (wz) is still summed on top, so strafe-while-
    turning works. Gait scheduler gates/ scales on combined planar speed.
    POC scope: failsafe path hardcodes vy=0 instead of a namespace-backed
    failsafe_vy tunable. Follow-up: add failsafe_vy to the controller
    namespace to restore the config-runtime contract; update controller
    docs chan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
    [main.c]
2026-09-11 docs: document FlySky stick assignment incl. strafe (vy); clarify failsafe_vy=0 by design
    Adds a concrete CH1-10 -> controller_state_t -> user_command_t mapping
    table to CONTROLLER_DRIVERS.md (previously only generic driver-arch
    guidance, no concrete stick assignment existed anywhere in docs). Also
    tightens the in-code comment: vy=0 on failsafe is a deliberate safety
    choice (no live stick => no safe non-zero strafe), not a gap to fill in
    with a namespace-backed failsafe_vy.
    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
2026-09-11 locomotion: quintic (minimum-jerk) horizontal swing sweep
    Replace the linear horizontal foot sweep during swing with a quintic
    smoothstep, giving zero foot velocity/acceleration at lift-off and
    touchdown instead of the instantaneous reversal the linear sweep had
    at the swing->support boundary (foot slip + servo shock). Same
    shaping applied to the yaw-turn sweep during swing.
    Also note observed mechanical issues (foot slip, coxa hinge play/Z
    sag) in docs/plans/TODO.md; tracked separately as a GH issue.
    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
2026-09-12 locomotion: Wilson gait continuum (continuous duty factor)
    Replace the 3 discrete gaits (tripod/ripple/wave) and their hardcoded
    duty factors / offset tables with a single continuum: swing fraction
    (duty factor) scales continuously with commanded speed, and per-leg
    phase offsets are derived from one formula (leg position in a
    canonical stepping order x duty factor) instead of a hardcoded table
    per gait.
    - gait_scheduler.c now computes duty_factor and leg_phase_offsets[]
    each tick from speed + new duty_factor_min/max config bounds.
    - swing_trajectory.c consumes those instead of its own
    switch(cmd->gait), removing duplicate gait-selection logic.
    - New gait namespace params: duty_factor_mi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
    [main.c]
2026-09-12 hardware: add TPU foot tip to leg model (FreeCAD)
    Part of the foot-slip fix tracked in GH issue #4 / docs/plans/TODO.md
    "Mechanical Improvements".
    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
    [hexapod_v2.FCStd]
2026-09-12 docs: update TODO — coxa hinge play fixed, TPU foot tip in progress
    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
